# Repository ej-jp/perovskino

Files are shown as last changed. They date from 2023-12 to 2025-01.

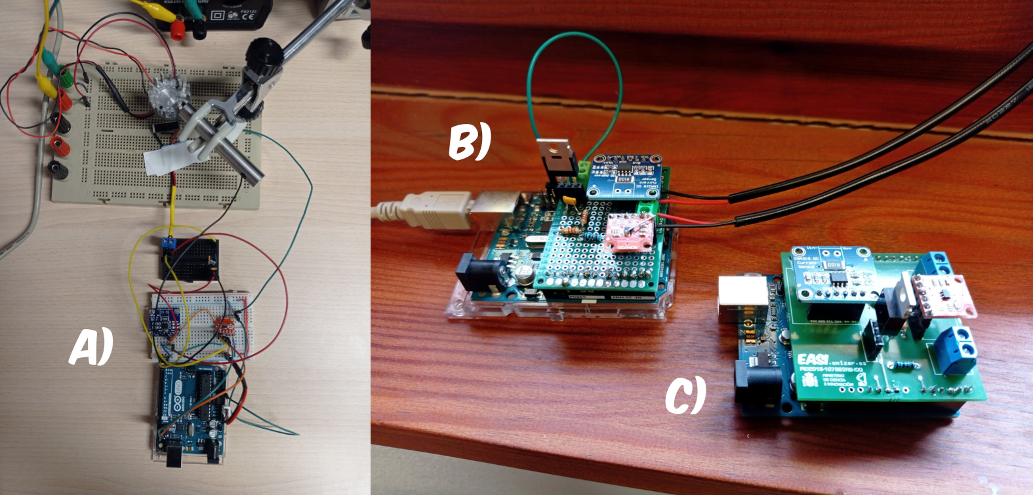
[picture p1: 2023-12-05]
Schematics-BOM-Gerbers/bread-perf-pcb-implementations.png

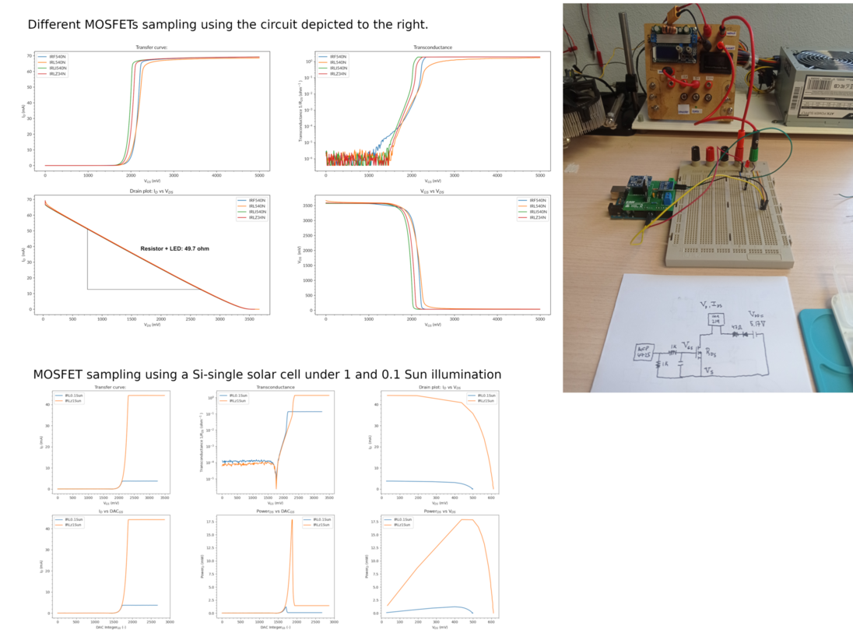
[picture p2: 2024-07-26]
codes/00_MOSFETS-Checker/Figure.png

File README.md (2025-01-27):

# perovskino
A Maximum Power Point Tracking (MPPT) algorithm and cost-effective hardware for long-term operational stability measurements in perovskite solar cells.

## Main article (algorithm):
*Enhanced power-point tracking for high-hysteresis perovskite solar cells with a galvanostatic approach*  
E. J. Juarez-Perez; C. Momblona; R. Casas and M. Haro.  
**Cell Reports Physical Science**, 2024, 5, 101885  
https://doi.org/10.1016/j.xcrp.2024.101885

## Protocol article (assembly and usage):
*Protocol for building and using a maximum power point output tracker for perovskite solar cells*  
A. Sanz-Marco; R. Jeronimo-Cruz; M. Haro and E. J. Juarez-Perez.  
**STAR Protocols**, 2024, 5, 103394  
https://doi.org/10.1016/j.xpro.2024.103394

## Initial Preprint:
https://doi.org/10.48550/arXiv.2312.03124

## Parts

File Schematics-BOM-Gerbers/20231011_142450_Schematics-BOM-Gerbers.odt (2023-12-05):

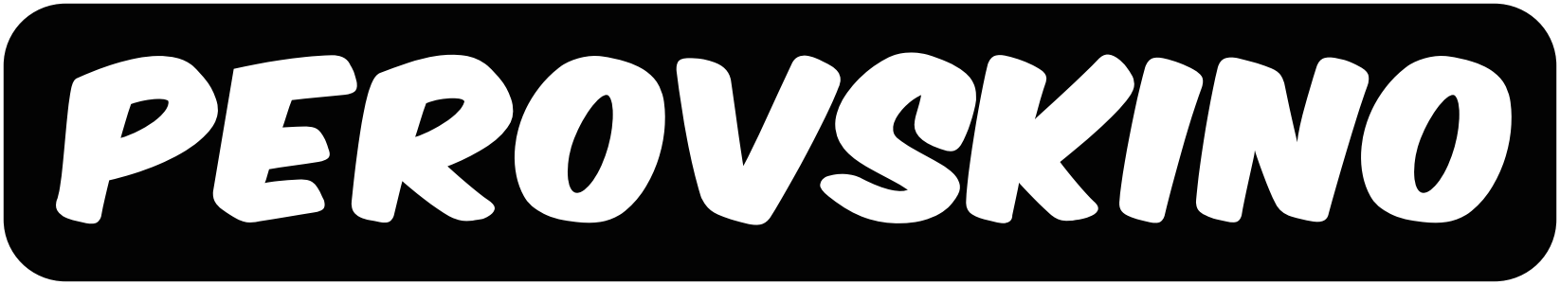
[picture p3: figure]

Version 1. 11/10/2023

Emilio J. Juarez-Perez, ejjuarezperez@unizar.es

## Schematic

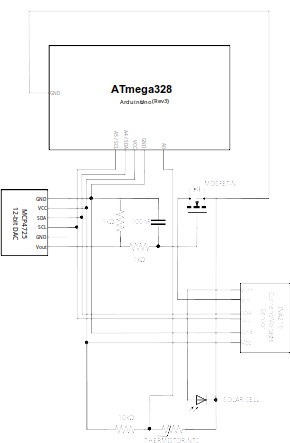
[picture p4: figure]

## Bill of Materials

Amount | Part Type | Properties
1 | ATmega328 | Atmel microchip as found in Arduino UNO (Rev3) or equivalent
1 | MCP4725 12-bit DAC | chip label MCP4725 Breakout; editable pin labels false; variant variant 2; pins 6
1 | INA219 DC Current Sensor Breakout | variant variant 5
1 | Basic FET N-Channel | package TO220 [THT]; type n-channel, IRLZ34N, IRLI540N
1 | Ceramic Capacitor | voltage 6.3V; capacitance 100nF; package 100 mil [THT, multilayer]
2 | 1kΩ Resistor | bands 4; tolerance ±5%; package THT; resistance 1kΩ; pin spacing 400 mil
1 | 10kΩ Resistor | bands 4; tolerance ±5%; package THT; resistance 10kΩ; pin spacing 400 mil
1 | Temperature Sensor (Thermistor) | resistance at 25° 10kΩ; package THT; type thermistor; thermistor type NTC
2 | Screw terminal - 2 pins | pin spacing 0.197in (5.0mm); hole size 1.0mm,0.508mm; package THT; pins 2

## Perovskino Shield 2209EJJP

https://aisler.net/p/VEECBBJB

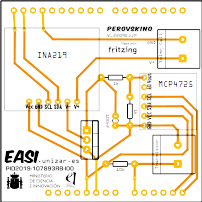
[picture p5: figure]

## Perovskino Shield 2304EJJP

https://aisler.net/p/SDRQAOGS

Update of the shield to accommodate various commercially available versions of MCP4725:

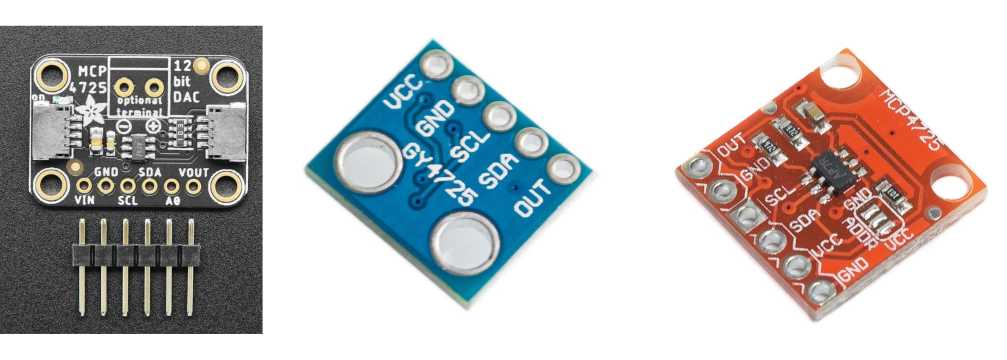
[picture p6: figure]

If employing the 5-pin Adafruit pin configuration, solder the pad connecting VGATE and pin 5.

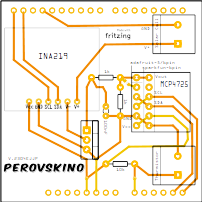
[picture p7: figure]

## Perovskino Perfboard Implementation

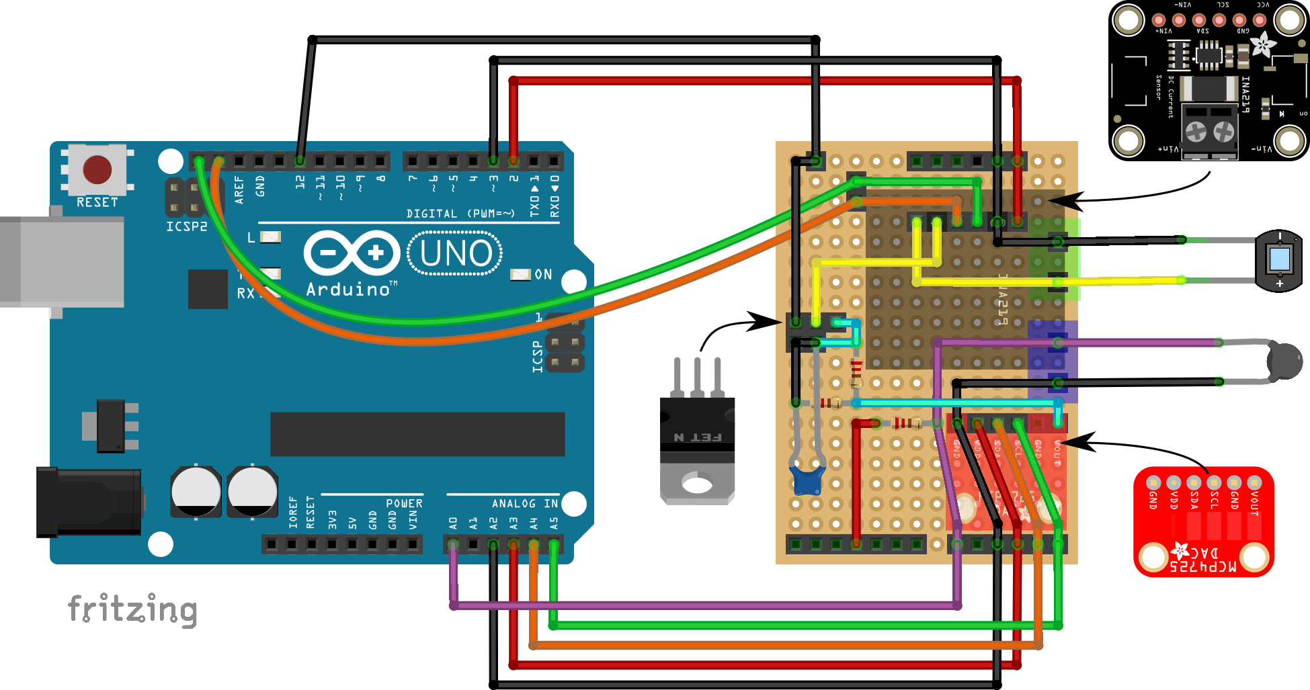
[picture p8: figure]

## LSH-7320 Oriel Solar Simulator

For inquiries regarding a program to conduct EN50530 illumination cycle tests in the LSH-7320 LED-based Oriel Solar Simulator, please contact ejjuarezperez@unizar.es

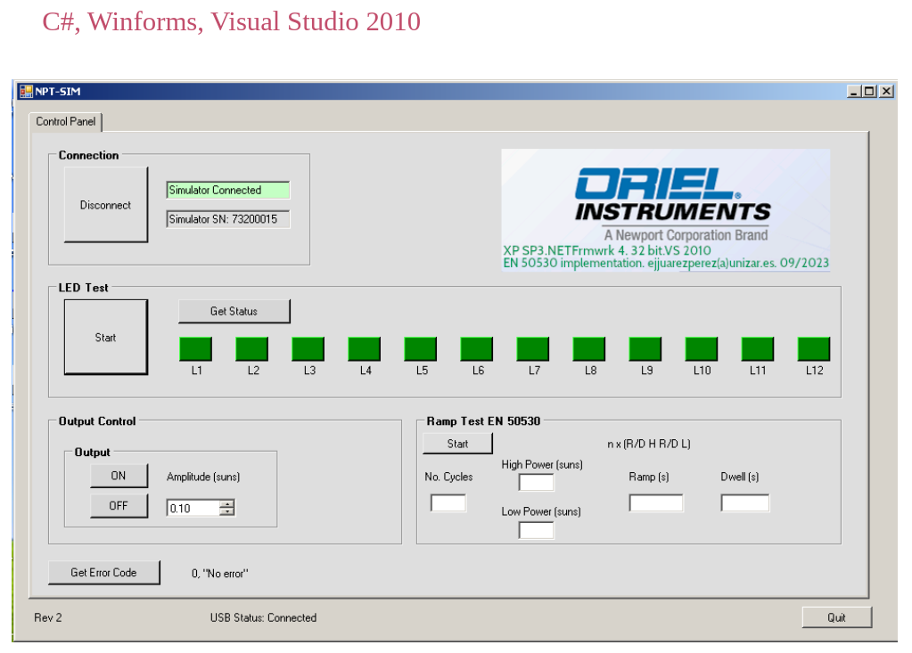
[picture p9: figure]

## Figures


Figure: a) bread-, b) perf- and c) printed circuit- board (PCB) implementations of the perovskino shield.

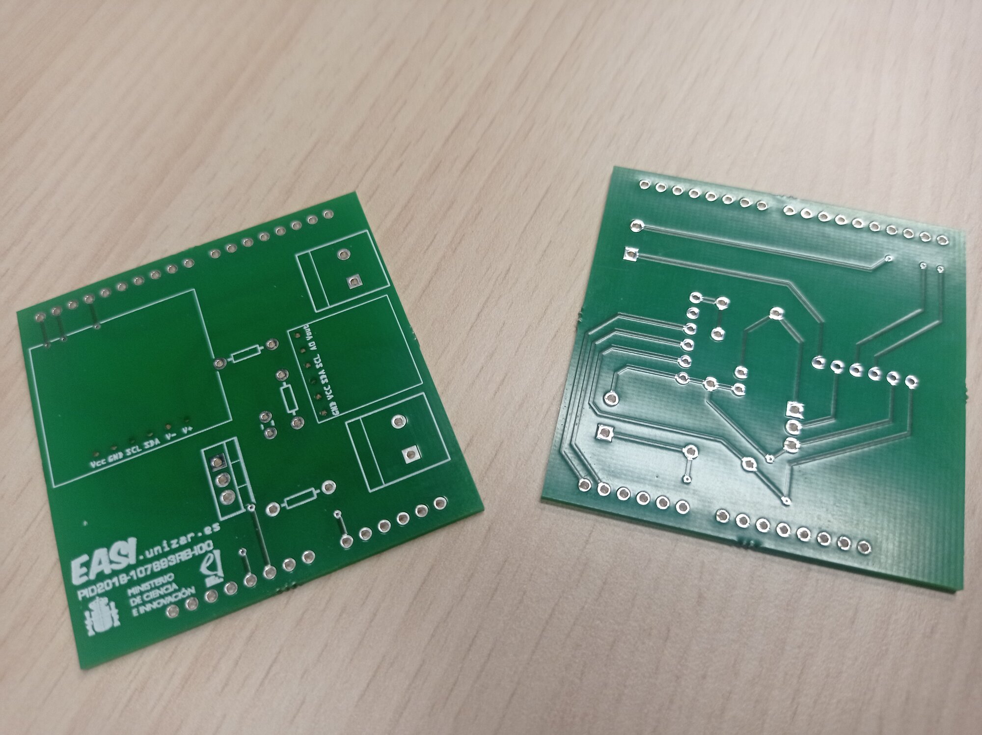
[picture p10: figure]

Figure: front and back of the perovskino shield (early version 0).


Figure: printed box with banana plugs for the Arduino + Perovskino shield.

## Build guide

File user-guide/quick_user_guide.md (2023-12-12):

# quick user guide
Perovskino is currently undergoing development; your patience is appreciated.

**Data logging**

1. Install Python 3.x (preferably from the Anaconda or Miniconda distribution <https://docs.conda.io/projects/miniconda/en/latest/miniconda-install.html> ) 
2. Dependencies for data logging and plotting will be pyserial (pip install pyserial) and Pandas, Matplotlib and Scipy (last three dependencies installed via conda install ...) 
3. Connect a solar cell in the Perovskino and plug it in one USB port of the computer.
4. Identify the assigned serial port for Perovskino (typically /dev/ttyUSB0 on Linux and COM3 in Windows, see Tips section below) .
5. Using the Anaconda Prompt or plain terminal in linux run: ``python capture-data-mpp-temperature.py`` in the ~/codes/02_MPP-algorithms/capture_and_grapher folder. The serial data is simultaneously displayed on the terminal window and stored in the dataraw folder as CSV files named date-time_hour.csv.
6. Utilize your preferred program or the grapherX.py scripts to plot the the CSV files stored in the dataraw folder (it is the default folder, change this folder modifying the corresponding line in the grapherX.py scripts)

**Data plotting**
Once we have obtained and stored data in the CSV files named date-time.csv we have two options to plot the obtained data using the scripts grapherX.py:

1. For graphing the previously obtained data execute: ``python grapher2.py`` 
2. If we want to plot the data while they are being obtained, open another anaconda terminal and execute ``python grapher4_alive.py`` 

**Tips:**

1. Easily determine the serial address assigned to the Arduino on the computer by installing the Arduino IDE ( <https://www.arduino.cc/en/software>) and checking the tools/port menu. Later, this IDE is used for reprogramming the micro-controller to upload modified SOP or PO .ino sketches. Once the serial port is known, modify the line number 8 in the file ~/codes/02_MPP-algorithms/capture_and_grapher/capture-datos-mpp-temperature.py accordingly if necessary.
2. Stop capturing data using control + C
3. If we have a problem graphing with grapher4_alive.py related with “Lato font” open the grapher4_alive.py in notebook and comment the corresponding line #plt.reParams[“font.family”]=”Lato”
4. If there’s any package or library not included in the Anaconda an error message will show up. Install them using pip or conda as required.
5. Data logging is obtained without device area normalization. Modify the variable square centimeters 'area' in the grapherX.py scripts for area normalization.

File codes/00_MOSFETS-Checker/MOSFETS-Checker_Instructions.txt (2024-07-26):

MOSFET Checker Procedure:

To verify that selected MOSFET works ok.
 
1. Construct the circuit according to the schematic presented in Figure.png or attach a single Si-cell under ~ 1 Sun illumination.
2. Utilize the Arduino IDE to upload the file mosfet-checker-ino/mosfet-checker-ino.ino.
3. Connect the MOSFET for evaluation.
4. Apply approximately 5 V to power the circuit or illuminate the cell under 1 Sun.
5. Commence data acquisition by executing capture_and_grapher/capture-datos.py. Edit the script to reflect the correct serial USB port on the computer assigned to the perovskite jig if needed.
6. Generate graphs based on the collected data using capture_and_grapher/grapher2.py.
7. Repeat the process using Si-cell under 0.1 Sun to find the correct DAC integer range to be applied in the VGATE.
8. Select the DAC interval and generate the VGATE list for SOP or PO MPP scripts using generate_dac_lists4SOP.py or generate_dac_lists4PO.py, respectively.

Notes:

Examples of broken ILZN43N MOSFETS can be found dataraw folder.
Hint: A working MOSFET shows a smooth JV curve for Si-cell under 1 Sun without spikes.

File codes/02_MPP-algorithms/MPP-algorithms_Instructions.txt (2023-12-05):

Procedure to run SOP, SOP-manual, and P&O MPPT Algorithms in the Perovskino.

**Preliminary Steps for First Time Setup:**

1. Execute the MOSFETS-Checker routine to determine appropriate minimal DAC step values and intervals required to bias the MOSFET gate for full open and close state.

2. Calibrate the INA219 breakout device as outlined in the INA219-Calibration procedure.

**Procedure for Running MPP Algorithms:**

1. Upload the corresponding ino file for the desired measurement type (SOP, SOP-manual, or P&O) to the Arduino jig equipped with the Perovskino shield.

2. Attach the solar cell and thermistor as needed.

3. Validate that the DAC step sequence, limits and intervals for the MOSFET from the MOSFETS-Checker routine align with the DAC_lists hardcoded in the ino file. These DAC_lists define the VGATE values tested during the JV stage.

4. The SOP algorithm supports up to 8 types of VGATE scans for the JV stage including BWD, FWD, BWD-FWD, and FWD-BWD, with two different interval resolutions. The variable countermpp obtained from mppcalculation() stores the DAC step yielding maximum power.

5. In contrast, the mppcalculation() in the P&O algorithm performs BWD and FWD voltage scans, with countermpp representing the averaged maximum for each scan.

6. The mppcalculation() function is interchangeable between SOP and P&O algorithms.

7. SOP-manual algorithm is similar to the SOP algorithm but allows manual setting of the countermpp variable using the "echo "0" > optimo-DAC.txt | python send-serial-opt.py" command in the "02_MPP-algorithms/manual-inputs" folder overriding the value obtained from mppcalculation().

**Data Extraction and Storage:**

Utilize the "capture-datos-mpp-temperature.py" Python script in the "02_MPP-algorithms/capture_and_grapher" folder to capture and store the data. Run the script with "python capture-datos-mpp-temperature.py". Verify and modify the serial address of your computer to the Arduino (/dev/ACMX or /dev/USBX) if necessary. The data is displayed in the terminal and stored in the "dataraw" folder. An hourly CSV file is generated to prevent data loss.

**Grapher Utilities:**

Several programs can be utilized to graph the data stored as CSV in the "dataraw" folder. However, it is recommended to use the scripts of the form "grapherX.py."

- **grapher2.py:**
  This script is advisable for post-measurement analysis. It generates a graph with nine panels displaying key variables from the solar cell, transfer curves, and temperature. The graphs showcase the time evolution of the data, presented with date-time formatting, and include intervals without data.

- **grapher3_rebase.py and grapher3_rebase_wDetector.py:**
  Scripts of the "grapher3" type, akin to grapher2, but they rebase time to seconds from the initial time, and any gaps in the data are removed. The grapher3_rebase_wDetector.py allows data coming from other solar cell detecting irradiation power during EN-50530 tests (see below).

- **grapher4_alive.py:**
  Similar to grapher2, this script can run and provide real-time updates during the measurement. The "pause_seconds.txt" file configures the time intervals between graph updates, enhancing monitoring capabilities.

**Other Relevant Information:**

For inquiries regarding a program to conduct EN50530 illumination cycle tests in the LSH-7320 LED-based Oriel Solar Simulator, please contact ejjuarezperez@unizar.es.

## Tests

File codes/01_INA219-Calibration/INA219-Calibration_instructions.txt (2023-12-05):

Procedure for INA219 Calibration (Voltage and Current Measurement):

1. Assemble the complete Perovskino jig and connect a Silicon cell or other stable cell.
2. Position the multimeter appropriately with respect to the solar cell for either voltage (parallel) or current (series) calibration measurements.
3. Employ the Arduino Integrated Development Environment (IDE) to upload the file "INA219-calibration-ino.ino" in the Perovskino. Modify this file based on the voltage or current calibration requirements assuring that correcV and correcI parameters are 0 and 1, respectively

4. Initiate data acquisition by executing the "capture-datos-INA219_calibration.py" script.
5. Data visualization can be performed using scripts of the "grapher" type.

6. For current calibration, set the MCP4725 to a voltage higher than the threshold voltage of the MOSFET to induce a short circuit condition in the solar cell.
7. Adjust irradiation levels while recording the current values from both the multimeter and INA219.
8. Calculate the correct current parameter (correcI) as the slope derived from linearly fitting the multimeter and INA219 data. Refer to the "calc INA219_calibration.ods" file for an example.

9. For voltage calibration, configure the MCP4725 to a voltage below the threshold voltage of the MOSFET to achieve an open circuit condition in the solar cell.
10. Vary irradiation while noting the voltage values from both the multimeter and INA219.
11. Determine the correct voltage parameter (correcV) as the ordinate at the origin from linearly fitting the multimeter and INA219 data, using a line equation with a slope of 1. Refer to the "calc INA219_calibration.ods" file for an example.

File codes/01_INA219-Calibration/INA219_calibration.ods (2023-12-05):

Current correction (correcI)
Perovskino (mA) | multimeter (mA)
32.12 | 28.2
27.3 | 24.3
22.52 | 19.9
20.6 | 18.11
16.2 | 14.24
13.63 | 11.98
13.05 | 11.48
9.9 | 8.63
5.95 | 5.24
2.62 | 2.3
0.5 | 0.38
0.49 | 0.37
0.19 | 0.11 |  | 31/03/2023
0.07 | 0 |  | correcI | 0.8816 | -
 |  |  | correcV | 25.28 | mV
Voltage correction (correcV)
Perovskino (mV) | multimeter (mV) | Fit slope = 1
568.5 | 591.8 | 593.8
479.5 | 502 | 504.8
466 | 489.1 | 491.3
463 | 487 | 488.3
453.8 | 483 | 479.1
447 | 480 | 472.3
437 | 468 | 462.3
426 | 458 | 451.3
426 | 459 | 451.3
415 | 437.5 | 440.3
387.73 | 410.5 | 413.0
332.5 | 355.4 | 357.8
273.6 | 296.5 | 298.9
210.5 | 232.8 | 235.8
189.6 | 212.2 | 214.9
187.2 | 210 | 212.5
129 | 151.8 | 154.3
106.12 | 128.5 | 131.4
0 |  | 25.28
AVG: | AVG:
355.4 | 380.7

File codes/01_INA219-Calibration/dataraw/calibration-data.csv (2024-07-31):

2023-12-01 19:32:26.307446 | MPP | 4095 | 5000.00 | 0.56 | 5.92 | 0.00 | 4095 | 0.00
2023-12-01 19:32:26.353194 | MPP | 4095 | 5000.00 | 0.61 | 5.50 | 0.00 | 4095 | 0.00
2023-12-01 19:32:26.570083 | MPP | 4095 | 5000.00 | 0.60 | 5.91 | 0.00 | 4095 | 0.00
2023-12-01 19:32:26.786954 | MPP | 4095 | 5000.00 | 0.56 | 5.91 | 0.00 | 4095 | 0.00
2023-12-01 19:32:27.003699 | MPP | 4095 | 5000.00 | 0.62 | 5.81 | 0.00 | 4095 | 0.00
2023-12-01 19:32:27.220755 | MPP | 4095 | 5000.00 | 0.57 | 5.83 | 0.00 | 4095 | 0.00
2023-12-01 19:32:27.437480 | MPP | 4095 | 5000.00 | 0.61 | 5.81 | 0.00 | 4095 | 0.00
2023-12-01 19:32:27.654556 | MPP | 4095 | 5000.00 | 0.56 | 5.75 | 0.00 | 4095 | 0.00
2023-12-01 19:32:27.871098 | MPP | 4095 | 5000.00 | 0.56 | 5.94 | 0.00 | 4095 | 0.00
2023-12-01 19:32:28.088088 | MPP | 4095 | 5000.00 | 0.60 | 5.75 | 0.00 | 4095 | 0.00
2023-12-01 19:32:28.304885 | MPP | 4095 | 5000.00 | 0.61 | 5.94 | 0.00 | 4095 | 0.00
2023-12-01 19:32:28.521946 | MPP | 4095 | 5000.00 | 0.60 | 5.49 | 0.00 | 4095 | 0.00
2023-12-01 19:32:28.738721 | MPP | 4095 | 5000.00 | 0.61 | 5.86 | 0.00 | 4095 | 0.00
2023-12-01 19:32:28.955582 | MPP | 4095 | 5000.00 | 0.53 | 5.95 | 0.00 | 4095 | 0.00
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

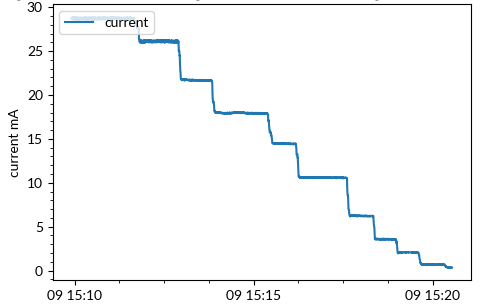
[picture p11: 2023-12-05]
codes/01_INA219-Calibration/Figure_1.png

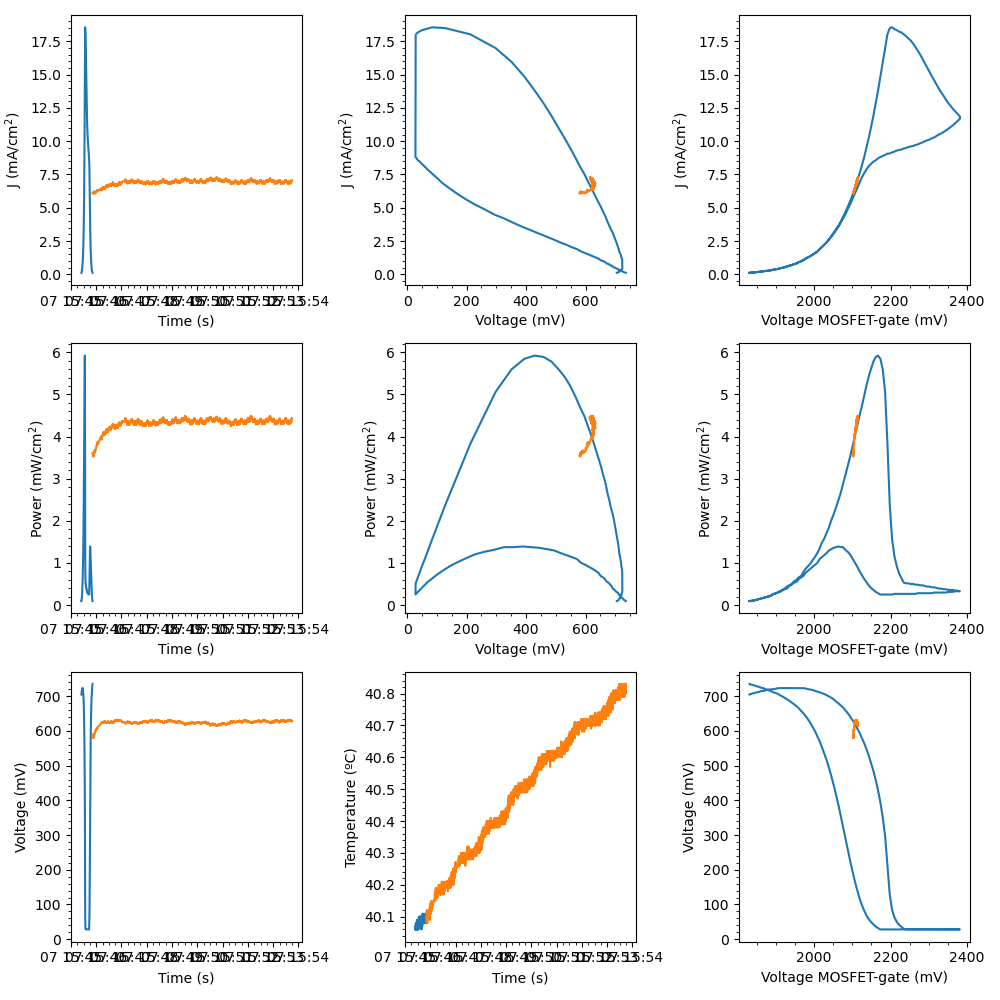
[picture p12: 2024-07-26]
codes/02_MPP-algorithms/capture_and_grapher/test.png

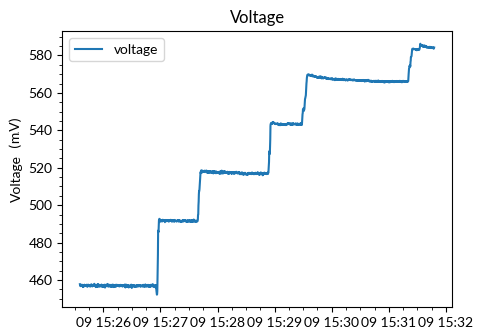
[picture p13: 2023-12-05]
codes/01_INA219-Calibration/Figure_2.png

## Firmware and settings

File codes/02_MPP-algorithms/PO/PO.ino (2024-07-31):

#include <Wire.h>
#include <math.h>
#include <Adafruit_MCP4725.h>
#include <Adafruit_INA219.h>
#include "dac_lookup_lists4PO.h"

//#include <LTR390.h>
//#include <DHT.h>

const char *arduinoID = "exampleID";


//Solar cell testing
Adafruit_MCP4725 dac;
Adafruit_INA219 ina219(0x40);

//Thermistors settings
//Sourcingmap – a14092200ux0209 10 K Ohm 0,05 W
//NTC Thermistor;Model : MF52-103;Insulation Material : Ceramic
//Color : Black;Rated Power : 0.05W;Resistance Value : 10K Ohm
//B Value : 3435(+/-1%);Pin Pitch : 1.5mm / 0.059""
const int Rc = 10000; //resistance value of the voltage divider
const float Vcc = 5.0;//input voltage of the voltage divider (arduino)
const int SensorPIN = A0;//voltage readings for thermistor in solar cell testing
//Thermistor parameters
#define A 1.098E-03
#define  B 2.446E-04
#define  C -3.693E-09



//ina219 calibration parameters
const float correcI = 0.84253;
const float correcV = 27.38;


//settings for PO-MPP algorithm search
const int n_average =30; //30; number of averaged measurements per data point; beta parameter
const int steps = 15;     //5; number of averaged data points constituting a k-step; delta parameter; 10 steps of MPP run ~2 seconds
const int stepcounter = 1;//2;  steps increment; epsilon parameter

//settings for PO-MPP algorithm search. Si-cell stable 38 min
//const int n_average =30; //30; number of averaged measurements per data point; beta parameter
//const int steps = 15;     //5; number of averaged data points constituting a k-step; delta parameter; 10 steps of MPP run ~2 seconds
//const int stepcounter = 1;//2;  steps increment; epsilon parameter

//Definition of the optimal DAC integer (VGATE)
int countermpp;

//Timing triggers
unsigned long startMillis;
unsigned long currentMillis;

const unsigned long longperiod = 10800000;  //180 min. Portion of time running at MPP condition between MPP search runs.
const unsigned long shortperiod = 3000; // below this time the system is just starting


void setup() {
  Serial.begin(9600);

  //Adafruit MCP4725A dac checkings
  if (! dac.begin(0x60)) {
    Serial.println("Failed to find MCP4725");
    while (1) {
      delay(10);
    }
  }
  dac.begin(0x60);

  //Adafruit INA219 checkings
  if (! ina219.begin()) {
    Serial.println("Failed to find INA219");
    while (1) {
      delay(10);
    }
  }
  ina219.setCalibration_16V_400mA();

  startMillis = millis();
  
  // sending arduino ID
  //Serial.println(arduinoID);
  //Serial.println(arduinoID);
  //Serial.println(arduinoID);
  //Serial.println(arduinoID);

}

void loop() {
  currentMillis = millis();

  //search of the MPP voltage
  if  ((currentMillis - startMillis <= shortperiod) || (currentMillis - startMillis >= longperiod)) {
    //if the device has just started up or
    //if the MPP point holding time has passed the long period
    //then launch the MPP search function again.
    countermpp = mppcalculation();//JV and countermpp determination
    
    //Alternative to JV
    //countermpp = 1685;//skip JV

    startMillis = currentMillis;
  }

  // P&O MPPT algorithm
  countermpp = POmpp(countermpp);


}

// ################FUNCTIONS####################


int POmpp(int countermpp) {

  //variable storing the average power and voltage of each while run.
  float power_avg1 = 0.0;
  float power_avg2 = 0.0;
  float power_avg3 = 0.0;
  float voltg_avg1 = 0.0;
  float voltg_avg2 = 0.0;
  float voltg_avg3 = 0.0;

  // First while run, parameters definition
  int var = 0;
  
  while (var <= steps) {
    dac.setVoltage(countermpp, false);
    delay(10);

    float voltageapplied = countermpp * (5000.0 / 4095); //this maps the applied voltage in volts from 0 t 5000 mV
    float busvoltage = 0;
    float current_mA = 0;
    float shuntvoltage = 0;
    for (int i = 0; i < n_average; i++) {
      busvoltage = busvoltage + ina219.getBusVoltage_V() * 1000;
      current_mA = current_mA + ina219.getCurrent_mA();
      shuntvoltage = shuntvoltage + ina219.getShuntVoltage_mV();
      delay(1);
    }

    float busvoltagesc = busvoltage / n_average;
    float current_mAsc = ( correcI * current_mA ) / n_average;
    float shuntvoltagesc = shuntvoltage / n_average;
    float voltagesc = busvoltagesc + shuntvoltagesc + correcV;
    float power = voltagesc * current_mAsc / 1000.0; // mW
    delay(10);

    // Averaged power and voltage in the while loop
    if (var <= steps && var > 0) {// discards first measurement. 
      power_avg1 = power_avg1 + power;
      voltg_avg1 = voltg_avg1 + voltagesc;
    }
    if (var == steps) {
      power_avg1 = power_avg1 / steps;
      voltg_avg1 = voltg_avg1 / steps;
    }

    //solar cell temperature measurement each step in var while
    float temperature = termistorT();


    //serial output
    //Serial.print(arduinoID); Serial.print("\t");
    Serial.print("MPP"); Serial.print("\t");
    Serial.print(countermpp); Serial.print("\t");
    Serial.print(voltageapplied); Serial.print("\t");
    Serial.print(voltagesc); Serial.print("\t");
    Serial.print(current_mAsc); Serial.print("\t");
    Serial.print(power); Serial.print("\t");
    Serial.print(countermpp); Serial.print("\t");
    Serial.print(power); Serial.print("\t");
    Serial.println(temperature);

    var++;
  }

  //Serial.print("power_avg1: "); Serial.println(power_avg1);

  // Second while run, parameters definition
  var = 0;//restart variable
  countermpp = countermpp + stepcounter;// countermpp + epsilon parameter

  while (var <= steps) {
    dac.setVoltage(countermpp, false);
    delay(10);

    float voltageapplied = countermpp * (5000.0 / 4095); //this maps the applied voltage in volts from 0 t 5000 mV
    float busvoltage = 0;
    float current_mA = 0;
    float shuntvoltage = 0;
    for (int i = 0; i < n_average; i++) {
      busvoltage = busvoltage + ina219.getBusVoltage_V() * 1000;
      current_mA = current_mA + ina219.getCurrent_mA();
      shuntvoltage = shuntvoltage + ina219.getShuntVoltage_mV();
      delay(1);
    }

    float busvoltagesc = busvoltage / n_average;
    float current_mAsc = ( correcI * current_mA ) / n_average;
    float shuntvoltagesc = shuntvoltage / n_average;
    float voltagesc = busvoltagesc + shuntvoltagesc + correcV;
    float power = voltagesc * current_mAsc / 1000.0; // mW
    delay(10);

    // Averaged power and voltage in the while loop
    if (var <= steps && var > 0) {
      power_avg2 = power_avg2 + power;
      voltg_avg2 = voltg_avg2 + voltagesc;
    }                       
    if (var == steps) {     
      power_avg2 = power_avg2 / steps;
      voltg_avg2 = voltg_avg2 / steps;
    }

    //solar cell temperature measurement each step in var while
    float temperature = termistorT();


    //serial output
    //Serial.print(arduinoID); Serial.print("\t");
    Serial.print("MPP"); Serial.print("\t");
    Serial.print(countermpp); Serial.print("\t");
    Serial.print(voltageapplied); Serial.print("\t");
    Serial.print(voltagesc); Serial.print("\t");
    Serial.print(current_mAsc); Serial.print("\t");
    Serial.print(power); Serial.print("\t");
    Serial.print(countermpp); Serial.print("\t");
    Serial.print(power); Serial.print("\t");
    Serial.println(temperature);

    var++;
  }

  // Third while run, parameters definition
  var = 0;
  countermpp = countermpp - stepcounter;//comeback to original countermpp from while no. 1
  
  while (var <= steps) {
    dac.setVoltage(countermpp, false);
    delay(10);

    float voltageapplied = countermpp * (5000.0 / 4095); //this maps the applied voltage in volts from 0 t 5000 mV
    
    //init variables storing data measured by INA219
    float busvoltage = 0;
    float current_mA = 0;
    float shuntvoltage = 0;

    for (int i = 0; i < n_average; i++) {
      busvoltage = busvoltage + ina219.getBusVoltage_V() * 1000;
      current_mA = current_mA + ina219.getCurrent_mA();
      shuntvoltage = shuntvoltage + ina219.getShuntVoltage_mV();
      delay(1);
    }

    float busvoltagesc = busvoltage / n_average;
    float current_mAsc = ( correcI * current_mA ) / n_average;
    float shuntvoltagesc = shuntvoltage / n_average;
    float voltagesc = busvoltagesc + shuntvoltagesc + correcV;
    float power = voltagesc * current_mAsc / 1000.0; // mW
    delay(10);

    // Averaged power and voltage in the while loop
    if (var <= steps && var > 0) {
      power_avg3 = power_avg3 + power;
      voltg_avg3 = voltg_avg3 + voltagesc;
    }
    if (var == steps) {
      power_avg3 = power_avg3 / steps;
      voltg_avg3 = voltg_avg3 / steps;
    }

    //solar cell temperature measurement
    float temperature = termistorT();


    //serial output
    //Serial.print(arduinoID); Serial.print("\t");
    Serial.print("MPP"); Serial.print("\t");
    Serial.print(countermpp); Serial.print("\t");
    Serial.print(voltageapplied); Serial.print("\t");
    Serial.print(voltagesc); Serial.print("\t");
    Serial.print(current_mAsc); Serial.print("\t");
    Serial.print(power); Serial.print("\t");
    Serial.print(countermpp); Serial.print("\t");
    Serial.print(power); Serial.print("\t");
    Serial.println(temperature);

    var++;
  }


  //  P&O: choice of next countermpp
  float diffpower_avg =  power_avg2 - power_avg1;//difference detected in power between n and n + 1 step
  float diffvoltg_avg =  voltg_avg2 - voltg_avg1;//difference detected in voltage between n and n + 1 step
  float diffpower_avg_rcheck = power_avg3 - power_avg1;//difference detected in power  between n and n 
  
  countermpp = countermpp + stepcounter;//counter for the second while


  if (diffpower_avg >= 0.0 && diffvoltg_avg >= 0.0 )   {
    countermpp = countermpp;// if n+1 counter produces large power, set as the new countermpp for the next.
    if (countermpp >= maxlimitlist)   {
        return countermpp = maxlimitlist;//keeps limits
    }
    if (diffpower_avg_rcheck < 0.0) {
        return countermpp = countermpp - stepcounter - stepcounter; // if rechecking detects decrease of power, go back.
    }
    return countermpp;
  }
  
  if (diffpower_avg >= 0.0 && diffvoltg_avg < 0.0 )   {
    countermpp = countermpp;// if n+1 counter produces large power, set as the new countermpp for the next.
    if (countermpp >= maxlimitlist)   {
        return countermpp = maxlimitlist;//keeps limits
    }
    if (diffpower_avg_rcheck < 0.0) {
        return countermpp = countermpp - stepcounter - stepcounter; // if rechecking detects decrease of power, go back.
    }
    return countermpp;
  }
 
  if (diffpower_avg < 0.0 && diffvoltg_avg >= 0.0 )   {
    countermpp = countermpp - stepcounter - stepcounter;// if n+1 counter produces lower power, countermpp backs to n-1.
    if (countermpp <= minlimitlist)   {
        return countermpp = minlimitlist;//keeps limits
    }
    if (diffpower_avg_rcheck > 0.0) {
        return countermpp = countermpp + stepcounter + stepcounter; // if rechecking detects increase of power, go ahead.
    }
    return countermpp;
  }
  
  if (diffpower_avg < 0.0 && diffvoltg_avg < 0.0 )   {
    countermpp = countermpp - stepcounter - stepcounter;// if n+1 counter produces lower power, countermpp backs to n-1.
    if (countermpp <= minlimitlist)   {
        return countermpp = minlimitlist;//keeps limits
    }
    if (diffpower_avg_rcheck > 0.0) {
        return countermpp = countermpp + stepcounter + stepcounter; // if rechecking detects increase of power, go ahead.
    }
    return countermpp;
  }
}


int mppcalculation() { // JV loop with initial MPP determination
  float powermpp;// definition
  int countermpp = 0;// initial value to ensure that it picks up any positive value



  //Backward MPP determination
  powermpp = 0.0;// initial value to ensure that it picks up any positive value
  int countermpp_bwd = 0;// definition


  for (int j = 0; j < dac_steps2  ; j = j + 1) {
    int counter = pgm_read_word(&(DACLookup_list2[j]));
    dac.setVoltage(counter, false);// the dac sets the voltage on the mosfet
    delay(10);


    float voltageapplied = counter * (5000.0 / 4095); //this maps the applied voltage in volts from 0 t 5000 mV

    //init variables storing data measured by INA219
    float busvoltage = 0;
    float current_mA = 0;
    float shuntvoltage = 0;


    //n_average: number of measurements to be averaged
    for (int i = 0; i < n_average; i++) {
      busvoltage = busvoltage + ina219.getBusVoltage_V() * 1000;
      current_mA = current_mA + ina219.getCurrent_mA();
      shuntvoltage = shuntvoltage + ina219.getShuntVoltage_mV();

      delay(1);
    }
    float busvoltagesc = busvoltage / n_average;
    float current_mAsc = ( correcI * current_mA ) / n_average;
    float shuntvoltagesc = shuntvoltage / n_average;
    float voltagesc = busvoltagesc + shuntvoltagesc + correcV;
    float power = voltagesc * current_mAsc / 1000.0; // mW


    //Classic MPP Search. Fetch dac step recording the MPP  for the BWD curve
    if ((power >= powermpp)) {
      powermpp = power;
      countermpp_bwd = counter;
    }

    //solar cell temperature measurement
    float temperature = termistorT();


    //serial output
    //Serial.print(arduinoID); Serial.print("\t");
    Serial.print("JV"); Serial.print("\t");
    Serial.print(counter); Serial.print("\t");
    Serial.print(voltageapplied); Serial.print("\t");
    Serial.print(voltagesc); Serial.print("\t");
    Serial.print(current_mAsc); Serial.print("\t");
    Serial.print(power); Serial.print("\t");
    Serial.print(countermpp_bwd); Serial.print("\t");
    Serial.print(powermpp); Serial.print("\t");
    Serial.println(temperature);
  }


  //Forward MPP determination
  powermpp = 0.0;// initial value to ensure that it picks up any positive value
  int countermpp_fwd = 0;// definition


  for (int j = 0; j < dac_steps1  ; j = j + 1) {
    int counter = pgm_read_word(&(DACLookup_list1[j]));
    dac.setVoltage(counter, false);// the dac sets the voltage on the mosfet
    delay(10);


    float voltageapplied = counter * (5000.0 / 4095); //this maps the applied voltage in volts from 0 t 5000 mV

    //init variables storing data measured by INA219
    float busvoltage = 0;
    float current_mA = 0;
    float shuntvoltage = 0;


    //n_average: number of measurements to be averaged
    for (int i = 0; i < n_average; i++) {
      busvoltage = busvoltage + ina219.getBusVoltage_V() * 1000;
      current_mA = current_mA + ina219.getCurrent_mA();
      shuntvoltage = shuntvoltage + ina219.getShuntVoltage_mV();

      delay(1);
    }
    float busvoltagesc = busvoltage / n_average;
    float current_mAsc = ( correcI * current_mA ) / n_average;
    float shuntvoltagesc = shuntvoltage / n_average;
    float voltagesc = busvoltagesc + shuntvoltagesc + correcV;
    float power = voltagesc * current_mAsc / 1000.0; // mW


    //Classic MPP Search. Fetch dac step recording the MPP for the FWD curve
    if ((power >= powermpp)) {
      powermpp = power;
      countermpp_fwd = counter;
    }

    //solar cell temperature measurement
    float temperature = termistorT();


    //serial output
    //Serial.print(arduinoID); Serial.print("\t");
    Serial.print("JV"); Serial.print("\t");
    Serial.print(counter); Serial.print("\t");
    Serial.print(voltageapplied); Serial.print("\t");
    Serial.print(voltagesc); Serial.print("\t");
    Serial.print(current_mAsc); Serial.print("\t");
    Serial.print(power); Serial.print("\t");
    Serial.print(countermpp_fwd); Serial.print("\t");
    Serial.print(powermpp); Serial.print("\t");
    Serial.println(temperature);
  }
  // Average calculation between counter during MPP of the FWD and BWD branch
  int sum = countermpp_fwd + countermpp_bwd;
  countermpp = sum / 2 - 10; // temperature or fast/slow scan effect. 
  //countermpp = sum / 2 ; // conventional
  return countermpp;
}


float termistorT() {
  float raw = 0;
  for (int i = 0; i < 30; i++) {
    raw = raw + analogRead(SensorPIN);
    delay(1);
  }
  raw = raw / 30.0;
  float V =  raw / 1024 * Vcc;
  float R = (Rc * V ) / (Vcc - V);
  float logRR  = log(R);
  float kelvin = 1.0 / (A + B * logRR + C * logRR * logRR * logRR );
  float celsius = kelvin - 273.15;
  return celsius;
}

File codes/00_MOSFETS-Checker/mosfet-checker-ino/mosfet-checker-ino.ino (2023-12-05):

#include <Adafruit_MCP4725.h>
#include <Adafruit_INA219.h>


//breakouts name
Adafruit_MCP4725 dac;
Adafruit_INA219 ina219(0x40);


////Forward slow voltage scan
const int dac_steps1 = 4096;
const PROGMEM int DACLookup_list1[dac_steps1] =
{
0, 1, 2, 3, 4, 5, 6, 7, 8, 9, 10, 11, 12, 13, 14, 15, 16, 17, 18, 19, 20, 21, 22, 23, 24, 25, 26, 27, 28, 29, 30, 31, 32, 33, 34, 35, 36, 37, 38, 39, 40, 41, 42, 43, 44, 45, 46, 47, 48, 49, 50, 51, 52, 53, 54, 55, 56, 57, 58, 59, 60, 61, 62, 63, 64, 65, 66, 67, 68, 69, 70, 71, 72, 73, 74, 75, 76, 77, 78, 79, 80, 81, 82, 83, 84, 85, 86, 87, 88, 89, 90, 91, 92, 93, 94, 95, 96, 97, 98, 99, 100, 101, 102, 103, 104, 105, 106, 107, 108, 109, 110, 111, 112, 113, 114, 115, 116, 117, 118, 119, 120, 121, 122, 123, 124, 125, 126, 127, 128, 129, 130, 131, 132, 133, 134, 135, 136, 137, 138, 139, 140, 141, 142, 143, 144, 145, 146, 147, 148, 149, 150, 151, 152, 153, 154, 155, 156, 157, 158, 159, 160, 161, 162, 163, 164, 165, 166, 167, 168, 169, 170, 171, 172, 173, 174, 175, 176, 177, 178, 179, 180, 181, 182, 183, 184, 185, 186, 187, 188, 189, 190, 191, 192, 193, 194, 195, 196, 197, 198, 199, 200, 201, 202, 203, 204, 205, 206, 207, 208, 209, 210, 211, 212, 213, 214, 215, 216, 217, 218, 219, 220, 221, 222, 223, 224, 225, 226, 227, 228, 229, 230, 231, 232, 233, 234, 235, 236, 237, 238, 239, 240, 241, 242, 243, 244, 245, 246, 247, 248, 249, 250, 251, 252, 253, 254, 255, 256, 257, 258, 259, 260, 261, 262, 263, 264, 265, 266, 267, 268, 269, 270, 271, 272, 273, 274, 275, 276, 277, 278, 279, 280, 281, 282, 283, 284, 285, 286, 287, 288, 289, 290, 291, 292, 293, 294, 295, 296, 297, 298, 299, 300, 301, 302, 303, 304, 305, 306, 307, 308, 309, 310, 311, 312, 313, 314, 315, 316, 317, 318, 319, 320, 321, 322, 323, 324, 325, 326, 327, 328, 329, 330, 331, 332, 333, 334, 335, 336, 337, 338, 339, 340, 341, 342, 343, 344, 345, 346, 347, 348, 349, 350, 351, 352, 353, 354, 355, 356, 357, 358, 359, 360, 361, 362, 363, 364, 365, 366, 367, 368, 369, 370, 371, 372, 373, 374, 375, 376, 377, 378, 379, 380, 381, 382, 383, 384, 385, 386, 387, 388, 389, 390, 391, 392, 393, 394, 395, 396, 397, 398, 399, 400, 401, 402, 403, 404, 405, 406, 407, 408, 409, 410, 411, 412, 413, 414, 415, 416, 417, 418, 419, 420, 421, 422, 423, 424, 425, 426, 427, 428, 429, 430, 431, 432, 433, 434, 435, 436, 437, 438, 439, 440, 441, 442, 443, 444, 445, 446, 447, 448, 449, 450, 451, 452, 453, 454, 455, 456, 457, 458, 459, 460, 461, 462, 463, 464, 465, 466, 467, 468, 469, 470, 471, 472, 473, 474, 475, 476, 477, 478, 479, 480, 481, 482, 483, 484, 485, 486, 487, 488, 489, 490, 491, 492, 493, 494, 495, 496, 497, 498, 499, 500, 501, 502, 503, 504, 505, 506, 507, 508, 509, 510, 511, 512, 513, 514, 515, 516, 517, 518, 519, 520, 521, 522, 523, 524, 525, 526, 527, 528, 529, 530, 531, 532, 533, 534, 535, 536, 537, 538, 539, 540, 541, 542, 543, 544, 545, 546, 547, 548, 549, 550, 551, 552, 553, 554, 555, 556, 557, 558, 559, 560, 561, 562, 563, 564, 565, 566, 567, 568, 569, 570, 571, 572, 573, 574, 575, 576, 577, 578, 579, 580, 581, 582, 583, 584, 585, 586, 587, 588, 589, 590, 591, 592, 593, 594, 595, 596, 597, 598, 599, 600, 601, 602, 603, 604, 605, 606, 607, 608, 609, 610, 611, 612, 613, 614, 615, 616, 617, 618, 619, 620, 621, 622, 623, 624, 625, 626, 627, 628, 629, 630, 631, 632, 633, 634, 635, 636, 637, 638, 639, 640, 641, 642, 643, 644, 645, 646, 647, 648, 649, 650, 651, 652, 653, 654, 655, 656, 657, 658, 659, 660, 661, 662, 663, 664, 665, 666, 667, 668, 669, 670, 671, 672, 673, 674, 675, 676, 677, 678, 679, 680, 681, 682, 683, 684, 685, 686, 687, 688, 689, 690, 691, 692, 693, 694, 695, 696, 697, 698, 699, 700, 701, 702, 703, 704, 705, 706, 707, 708, 709, 710, 711, 712, 713, 714, 715, 716, 717, 718, 719, 720, 721, 722, 723, 724, 725, 726, 727, 728, 729, 730, 731, 732, 733, 734, 735, 736, 737, 738, 739, 740, 741, 742, 743, 744, 745, 746, 747, 748, 749, 750, 751, 752, 753, 754, 755, 756, 757, 758, 759, 760, 761, 762, 763, 764, 765, 766, 767, 768, 769, 770, 771, 772, 773, 774, 775, 776, 777, 778, 779, 780, 781, 782, 783, 784, 785, 786, 787, 788, 789, 790, 791, 792, 793, 794, 795, 796, 797, 798, 799, 800, 801, 802, 803, 804, 805, 806, 807, 808, 809, 810, 811, 812, 813, 814, 815, 816, 817, 818, 819, 820, 821, 822, 823, 824, 825, 826, 827, 828, 829, 830, 831, 832, 833, 834, 835, 836, 837, 838, 839, 840, 841, 842, 843, 844, 845, 846, 847, 848, 849, 850, 851, 852, 853, 854, 855, 856, 857, 858, 859, 860, 861, 862, 863, 864, 865, 866, 867, 868, 869, 870, 871, 872, 873, 874, 875, 876, 877, 878, 879, 880, 881, 882, 883, 884, 885, 886, 887, 888, 889, 890, 891, 892, 893, 894, 895, 896, 897, 898, 899, 900, 901, 902, 903, 904, 905, 906, 907, 908, 909, 910, 911, 912, 913, 914, 915, 916, 917, 918, 919, 920, 921, 922, 923, 924, 925, 926, 927, 928, 929, 930, 931, 932, 933, 934, 935, 936, 937, 938, 939, 940, 941, 942, 943, 944, 945, 946, 947, 948, 949, 950, 951, 952, 953, 954, 955, 956, 957, 958, 959, 960, 961, 962, 963, 964, 965, 966, 967, 968, 969, 970, 971, 972, 973, 974, 975, 976, 977, 978, 979, 980, 981, 982, 983, 984, 985, 986, 987, 988, 989, 990, 991, 992, 993, 994, 995, 996, 997, 998, 999, 1000, 1001, 1002, 1003, 1004, 1005, 1006, 1007, 1008, 1009, 1010, 1011, 1012, 1013, 1014, 1015, 1016, 1017, 1018, 1019, 1020, 1021, 1022, 1023, 1024, 1025, 1026, 1027, 1028, 1029, 1030, 1031, 1032, 1033, 1034, 1035, 1036, 1037, 1038, 1039, 1040, 1041, 1042, 1043, 1044, 1045, 1046, 1047, 1048, 1049, 1050, 1051, 1052, 1053, 1054, 1055, 1056, 1057, 1058, 1059, 1060, 1061, 1062, 1063, 1064, 1065, 1066, 1067, 1068, 1069, 1070, 1071, 1072, 1073, 1074, 1075, 1076, 1077, 1078, 1079, 1080, 1081, 1082, 1083, 1084, 1085, 1086, 1087, 1088, 1089, 1090, 1091, 1092, 1093, 1094, 1095, 1096, 1097, 1098, 1099, 1100, 1101, 1102, 1103, 1104, 1105, 1106, 1107, 1108, 1109, 1110, 1111, 1112, 1113, 1114, 1115, 1116, 1117, 1118, 1119, 1120, 1121, 1122, 1123, 1124, 1125, 1126, 1127, 1128, 1129, 1130, 1131, 1132, 1133, 1134, 1135, 1136, 1137, 1138, 1139, 1140, 1141, 1142, 1143, 1144, 1145, 1146, 1147, 1148, 1149, 1150, 1151, 1152, 1153, 1154, 1155, 1156, 1157, 1158, 1159, 1160, 1161, 1162, 1163, 1164, 1165, 1166, 1167, 1168, 1169, 1170, 1171, 1172, 1173, 1174, 1175, 1176, 1177, 1178, 1179, 1180, 1181, 1182, 1183, 1184, 1185, 1186, 1187, 1188, 1189, 1190, 1191, 1192, 1193, 1194, 1195, 1196, 1197, 1198, 1199, 1200, 1201, 1202, 1203, 1204, 1205, 1206, 1207, 1208, 1209, 1210, 1211, 1212, 1213, 1214, 1215, 1216, 1217, 1218, 1219, 1220, 1221, 1222, 1223, 1224, 1225, 1226, 1227, 1228, 1229, 1230, 1231, 1232, 1233, 1234, 1235, 1236, 1237, 1238, 1239, 1240, 1241, 1242, 1243, 1244, 1245, 1246, 1247, 1248, 1249, 1250, 1251, 1252, 1253, 1254, 1255, 1256, 1257, 1258, 1259, 1260, 1261, 1262, 1263, 1264, 1265, 1266, 1267, 1268, 1269, 1270, 1271, 1272, 1273, 1274, 1275, 1276, 1277, 1278, 1279, 1280, 1281, 1282, 1283, 1284, 1285, 1286, 1287, 1288, 1289, 1290, 1291, 1292, 1293, 1294, 1295, 1296, 1297, 1298, 1299, 1300, 1301, 1302, 1303, 1304, 1305, 1306, 1307, 1308, 1309, 1310,
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

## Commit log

2023-12-05 first upload
    [BOM.ods, INA219_calibration.ods, IRF540N.csv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]
2024-05-31 improvement grapher4alive, adding arduino ID for detection of /dev,adding reference to README.md
    [2024-05-31_14.csv, 2024-05-31_16.csv, IRL510.csv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]
2024-06-01 improvement MOSFET checker, example of broken MOSFET curve, improvement of DAClookup lists automated generation
    [2024-05-31_14.csv, 2024-05-31_16.csv]
2024-06-02 updated MOSFET Checker instructions
2024-06-02 improvements to PO algorithm
    [2024-06-02_03.csv]
2024-07-26 update correcting minor bugs and inconsistencies
    [2024-06-02_03.csv]
2024-07-31 update correcting minor bugs and inconsistencies2
    [IRF540N.csv, calibration-data.csv]
2025-01-27 modification in README.md, some dac_lookup_list
    [2024-07-29_16.csv]
